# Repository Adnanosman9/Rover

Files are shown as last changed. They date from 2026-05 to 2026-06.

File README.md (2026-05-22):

<p align="center">
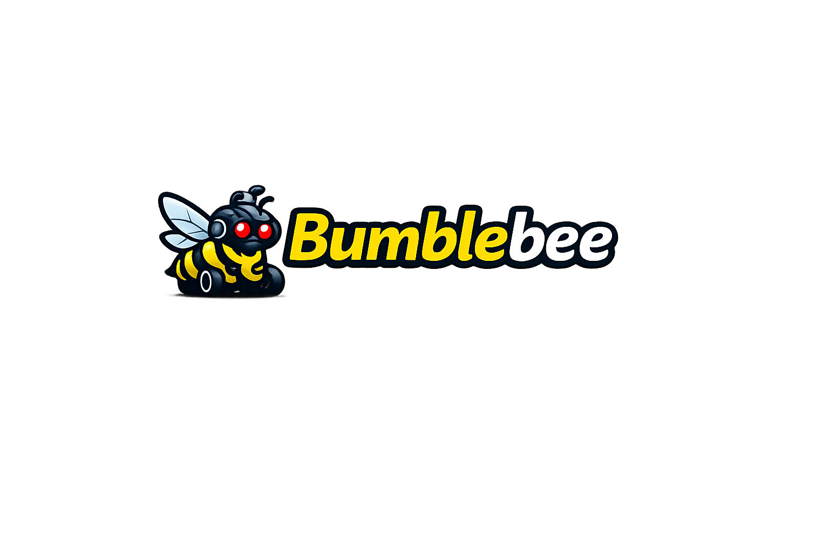
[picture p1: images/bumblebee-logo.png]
Bumblebee Logo
  
</p>

<h1 align="center">Bumblebee Rover</h1>

<p align="center">
Open-source modular autonomous rover platform based on the Sawppy Rover architecture,
adapted around affordable and locally available hardware in Bangladesh.
</p>

<p align="center">
  <a href="https://ohwr.org/cern_ohl_s_v2.txt">
    
  </a>
  <a href="https://hcb.hackclub.com/donations/start/bumblebee">
    
  </a>
  
  
</p>

Open-source modular autonomous rover chassis based on the [Sawppy Rover](https://github.com/Roger-random/Sawppy_Rover) architecture by [@Roger-random](https://github.com/Roger-random), redesigned around affordable and locally available hardware in Bangladesh.

---

<p align="center">
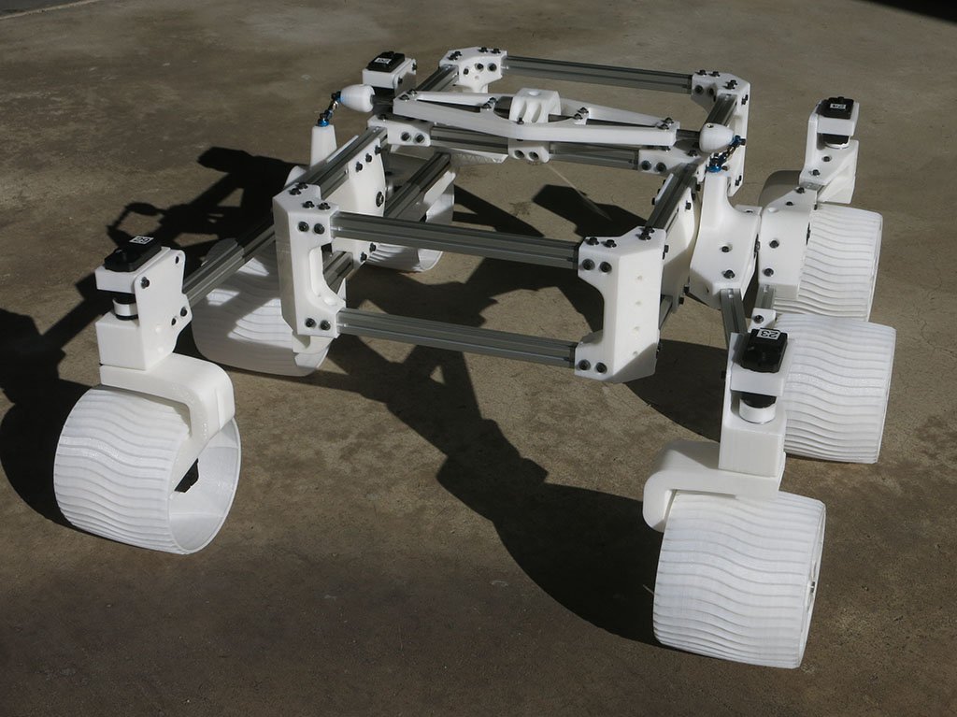
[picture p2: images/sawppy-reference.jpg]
Sawppy Rover Reference
  
</p>

### **Reference** [@Sawppy Rover](https://github.com/Roger-random/Sawppy_Rover/blob/main/docs/images/MechanicalChassis.jpg) by Roger Random, base chassis architecture this project is built on. 

---

## Overview

This is a student-led robotics project building a modular autonomous ground rover platform for robotics experimentation, autonomous navigation, and future competition adaptation.

Bumblebee is a derivative of the Sawppy Rover by Roger Random, replacing the original LX-16A smart servo drivetrain with JGB37-520 DC gear motors and Hiwonder LDX-227 PWM servos components that are significantly easier to source locally in Bangladesh at a fraction of the cost. Development files, CAD assets, documentation, and future electronics designs are intended to be published openly as the project progresses.

---

## Project Goals

- Build a functional rocker-bogie rover chassis adapted for local hardware
- Develop a reusable, modular rover platform for robotics experimentation
- Integrate ROS 2 for autonomous navigation and sensor fusion
- Publicly document the full engineering and prototyping process for other students and makers

---

## Key Features

- Rocker-bogie suspension system (Sawppy geometry, adapted mounts)
- Modular chassis architecture designed for payload expansion
- JGB37-520 12V 100RPM DC gear motor drivetrain (×6)
- Hiwonder LDX-227 PWM servo steering (×4)
- Standard 25T servo spline, no proprietary hardware
- Designed for ROS 2 integration and future autonomous navigation stack

---

## Major Changes from Sawppy

| Component | Sawppy Original | Bumblebee |
|---|---|---|
| Drive motor | LX-16A smart servo | JGB37-520 12V 100RPM DC gear motor |
| Steering | LX-16A smart servo | Hiwonder LDX-227 PWM servo |
| Motor control | Serial smart servo bus | BTS7960 |
| Servo spline | Proprietary | Standard 25T spline |
| Control MCU | - | Arduino or ESP |
| single board computer | - | Raspberry pi 4 4B |
| IMU | - | MPU-6050 |
| Hardware sourcing | Mostly imported | Locally available in Bangladesh |

---

## Hardware Stack

### Mobility
- 6× JGB37-520 12V 100RPM DC gear motors
- 4× Hiwonder LDX-227 PWM servos
- BTS7960 motor driver

### Structure
- Custom 3D printed components (PLA/PETG, ~3 kg)
- Aluminum extrusion frame
- Steel/aluminum shafts

### Electronics
- Raspberry Pi 4
- Arduino or ESP
- MPU-6050 IMU
- LiPo battery pack + BMS

### Software (Planned)
- ROS 2
- Autonomous navigation stack (GPS waypoints + SLAM)
- Sensor fusion
- Rover control interface

---

## Current Progress

### Completed
- Chassis architecture finalized
- Hardware selection completed
- Motor mount redesign
- Servo bracket redesign
- Steering linkage adaptation
- STEP files generated are available in [`/Step-files`](./Step-files)
- BOM completed
- Build log available in [`/Build log`](./Build%20log/architecture-journal.md)
- HCB fiscal sponsorship approved

### In Progress
- Structural component printing
- Chassis assembly

### Planned
- Drivetrain testing
- ROS 2 integration
- Autonomous navigation
- Field testing
- Payload expansion

---

## Why This Build Exists

Most capable open-source rover platforms - including the original Sawppy - rely on LX-16A or similar smart servos that are expensive and difficult to source reliably outside of the US, Europe, or China. Bumblebee is a direct answer to that problem: a full rocker-bogie rover platform adapted around hardware that is realistically accessible to students in Bangladesh.

The engineering tradeoffs are documented openly. This project is also intended to help other students and makers in similar situations adapt advanced robotics platforms to their local hardware ecosystem.

---

## Sponsorship

Bumblebee is fiscally sponsored by [Hack Club](https://hackclub.com), a 501(c)(3) nonprofit (EIN 81-2908499). **US donations are tax-deductible.**

We are currently seeking support for:

| What | Why it matters |
|---|---|
| Power and control | Batteries, converters, and motor drivers are currently major integration blockers |
| 3D printing | Structural parts, FDM in PLA/PETG |
| JGB37-520 motors + LDX-227 servos | Hard to source at consistent spec in Bangladesh |
| Sensors & compute | IMU, GPS, SBC for autonomous navigation stack |

For sponsorship details visit **→ [Sponsor page](https://adnanosman9.github.io/Bumblebee/sponsor.html)**
**→ [Donate directly via HCB](https://hcb.hackclub.com/donations/start/bumblebee)**

Sponsors receive logo placement on the project website and permanent credit in all documentation.

---

## Repository Structure

```
/
├── step-files/          # Fusion 360 source files and STEP exports
├── docs/         # Build logs and engineering notes
└── bom/          # Bill of materials
```
Additional firmware, electronics files, documentation, and testing data will be added progressively as development continues.
---

## License

Hardware designs in this repository are licensed under the **CERN Open Hardware Licence Version 2 - Strongly Reciprocal (CERN-OHL-S-2.0)**.

You are free to use, study, modify, and distribute this hardware and its documentation, provided that derivatives are released under the same license.

See [`LICENSE`](./LICENSE) for the full text, or visit [ohwr.org/cern_ohl_s_v2.txt](https://ohwr.org/cern_ohl_s_v2.txt).

---

## Acknowledgements

- [Roger Random (@Roger-random)](https://github.com/Roger-random) and the [Sawppy Rover](https://github.com/Roger-random/Sawppy_Rover) community — original architecture, suspension geometry, and open-source design philosophy
- [Hack Club HCB](https://hackclub.com/hcb) - fiscal sponsorship
- Open-source robotics and maker communities

---

## Author

**Adnan Osman** - [github.com/Adnanosman9](https://github.com/Adnanosman9)

Project website: [adnanosman9.github.io/Bumblebee](https://adnanosman9.github.io/Bumblebee/)

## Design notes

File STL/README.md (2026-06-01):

# Bill of Materials - Bumblebee Rover

> Based on the [Sawppy Rover](https://github.com/Roger-random/Sawppy_Rover) architecture by [@Roger-random](https://github.com/Roger-random), adapted for locally available hardware in Bangladesh.

---

## Printed Parts
~3 kg total filament (PLA or PETG)

| Qty | Part | Notes |
|-----|---|---|
| 88 | Clip2n125 | Print a few extra for spares |
| 12 | Clip3n20 | Print a few extra for spares |
| 6 | Wheel Hub | Print a few extra for spares |
| 4 | Servo Coupler | Print a few extra for spares |
| 4 | Servo Bracket | |
| 6 | Wheel | |
| 4 | Steering Knuckle | |
| 4 | Body Corner | |
| 2 | DiffBrace | |
| 2 | DiffLink | |
| 1 | DiffLower | |
| 1 | DiffUpper | |
| 2 | Rod Support | |
| 1 | Power Panel | |
| 2 | Fixed Knuckle | Mirrored |
| 2 | Front Corner | Mirrored |
| 2 | Rear Corner | Mirrored |
| 2 | Bogie Wheels | Mirrored |
| 2 | Bogie Body | Mirrored |
| 2 | Rocker | Mirrored |
| 2 | Rocker Body Mount | Mirrored |
| 2 | DiffEnd | Mirrored |
| 2 | Battery Tray | Mirrored |
| 6 | JGB37-520 Motor Bracket | Redesigned mount · not yet designed, pending physical measurements |
| 6 | JGB37-520 Motor Coupler | Wheel-to-motor connection · not yet designed, pending physical measurements |

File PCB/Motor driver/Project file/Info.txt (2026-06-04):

Project Title: 		Dual_Motor_Driver
Borard Title: 		Board1
PCB Title: 		PCB1
Time: 		2026-06-04 21:03:17

Borard Size: 		58.713mm x 60.025mm
Layers: 		Total 24, Copper 4

Devices: 		44
Footprints: 		33
Components: 		Total 125,Top Layer 105,Bottom Layer 20
Pads: 		Total 457, Top Side Table Stick 342,Bottom Side Table Stick 98,Metallized Hole 17, Nonmetallic Hole 0
Nets: 		Total 96, Unrouted 0
Test Point: 		Nets Total 96, Has Testpoint Nets 0, Testpoint Coverage 0%
 		Total 0, Top Side Testpoints 0, Bottom Side Testpoints 0

Slot Region: 		2
Vias: 		Total 526, Through Vias 526, Blind Or Buried Vais 0
CopperAreas: 		6
Length of Tracks: 		1732.224mm

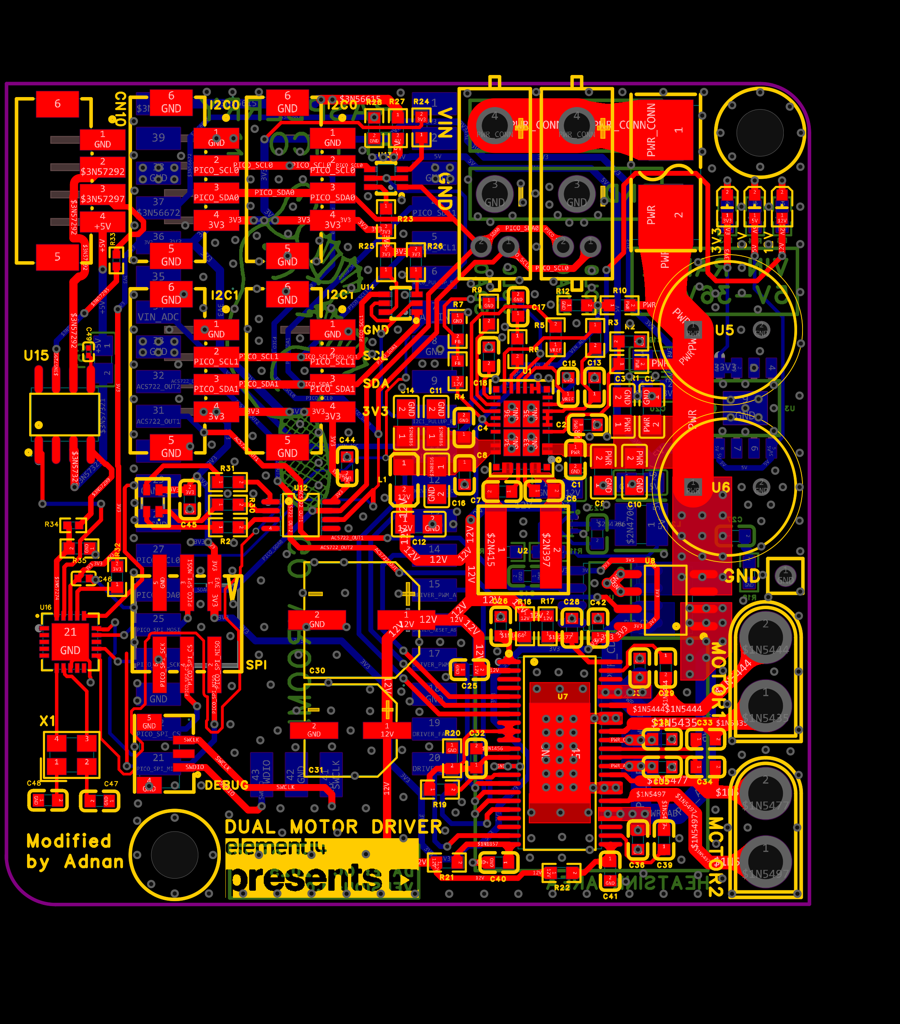
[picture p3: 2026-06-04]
PCB/Motor driver/images/Motor-Driver.png

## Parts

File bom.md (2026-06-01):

# Bill of Materials — Bumblebee Rover

> Based on the [Sawppy Rover](https://github.com/Roger-random/Sawppy_Rover) architecture by [@Roger-random](https://github.com/Roger-random), adapted for locally available hardware in Bangladesh.

---

## Printed Parts
~3 kg total filament (PLA or PETG)

| Qty | Part | Notes |
|-----|---|---|
| 88 | Clip2n125 | Print a few extra for spares |
| 12 | Clip3n20 | Print a few extra for spares |
| 6 | Wheel Hub | Print a few extra for spares |
| 4 | Servo Coupler | Print a few extra for spares |
| 4 | Servo Bracket | |
| 6 | Wheel | |
| 4 | Steering Knuckle | |
| 4 | Body Corner | |
| 2 | DiffBrace | |
| 2 | DiffLink | |
| 1 | DiffLower | |
| 1 | DiffUpper | |
| 2 | Rod Support | |
| 1 | Power Panel | |
| 2 | Fixed Knuckle | Mirrored |
| 2 | Front Corner | Mirrored |
| 2 | Rear Corner | Mirrored |
| 2 | Bogie Wheels | Mirrored |
| 2 | Bogie Body | Mirrored |
| 2 | Rocker | Mirrored |
| 2 | Rocker Body Mount | Mirrored |
| 2 | DiffEnd | Mirrored |
| 2 | Battery Tray | Mirrored |
| 6 | JGB37-520 Motor Bracket | Redesigned mount · not yet designed, pending physical measurements |
| 6 | JGB37-520 Motor Coupler | Wheel-to-motor connection · not yet designed, pending physical measurements |

---

## Shafts
Steel for differential shaft. Aluminum or steel for all others.

| Qty | Length (mm) | Part |
|-----|---|---|
| 1 | 300 | Differential Shaft |
| 6 | 50 | Wheel Axle Shaft |
| 4 | 61 | Steering Shaft |
| 2 | 66.5 | Suspension Bogie Pivot |
| 2 | 84 | Suspension Rocker Pivot |

---

## Hardware & Electronics

| Qty | Part | Notes |
|-----|---|---|
| 6 | JGB37-520 12V 100RPM DC Gear Motor | Drive |
| 4 | Hiwonder LDX-277 PWM Servo | Steering |
| 6 | Motor Shaft Couplers | JGB37-520 D-shaft compatible |
| 3 | BTS7960 43A Motor Driver Module | Paired motors per driver (2 motors × 3 drivers) |
| 1 | XIAO ESP32-C3 | Main control MCU |
| 1 | MPU-6050 | IMU |
| 1 | 12V LiPo Battery Pack | |
| 1 | Battery Management System (BMS) | 12V compatible |
| 30 | 608 Bearings | |
| 300 | M3×8mm Socket Head Screws | |
| 28 | M3×16mm Socket Head Screws | |
| 300 | M3 Washers + Nuts | |
| 100 | M3 Threaded Inserts | |
| 100 | 5/16" E-Clips | |
| 22 | M3×8 Set Screws | |
| 2 | Turnbuckles | Steering linkage |
| 40 | 1/4" Brass Screws | |

---

## Aluminum Extrusion
Standard 15mm or 20mm V-slot / T-slot profile.

| Qty | Length (mm) | Purpose |
|-----|---|---|
| 4 | 385 | Main body, lengthwise |
| 4 | 245 | Main body, widthwise |
| 1 | 238 | Differential fixed beam |
| 2 | 182 | Rocker joint to front wheel |
| 2 | 161 | Rocker joint to bogie joint |
| 2 | 122 | Bogie joint to middle wheel |
| 2 | 117 | Bogie joint to rear wheel |

---

## Notes

- **Motor Bracket & Coupler** — not yet designed. Will be modeled after physical parts are printed and measured.
- **BTS7960 wiring** — 3 drivers handle 6 motors in pairs (left-front+right-front, left-mid+right-mid, left-rear+right-rear). Each driver needs RPWM, LPWM, R_EN, L_EN from the ESP32-C3 — 12 GPIO pins total for drive.
- **608 bearings** — standard inline skate bearings, widely available locally.
- Printed part STEP files: [`/cad`](./cad)

---

*Bumblebee is fiscally sponsored by [Hack Club HCB](https://hcb.hackclub.com/donations/start/bumblebee) (501(c)(3) · EIN 81-2908499). Manufacturing sponsorships welcome — [sponsor page](https://adnanosman9.github.io/Bumblebee/sponsor.html).*

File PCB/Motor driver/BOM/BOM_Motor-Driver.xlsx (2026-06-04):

No. | Quantity | Comment | Designator | Footprint | Value | Manufacturer Part | Manufacturer | Supplier Part | Supplier | Category | Primary Category | LCSC Price | LCSC Stock | JLCPCB Stock | JLCPCB Price | Layer | Mounting Style | Pin Count | Add into BOM | Convert to PCB | 3D Model Title | Device | Name | Unique ID | Brand | Belt length
1 | 1 | 1PinHeader | 1PinHeader | 1PinHeader |  |  |  |  |  | Symbols Padronizados: | Symbols Padronizados | 0.0183 |  |  |  | T | DIP | 1 | yes |  |  | 1PinHeader |  | gge247
2 | 13 | 100nF | C1,C2,C4,C6,C7,C8,C18,C32,C35,C36,C37,C38,C42 | C0603 | 100nF | CL10B104KB8NNNC | SAMSUNG(三星) | C1591 | LCSC | Capacitors:Multilayer Ceramic Capacitors MLCC - SMD/SMT | Capacitors |  |  | 1077047 | 0.001 | T | SMT | 2 | yes |  | C0603_L1.6-W0.8-H0.8 | CL10B104KB8NNNC | 100nF | gge153,gge154,gge159,gge161,gge162,gge170,gge171,gge203,gge219,gge220,gge221,gge222,gge231
3 | 4 | 10uF | C3,C5,C9,C10 | C0805 | 10uF |  |  |  |  | Capacitors:Multilayer Ceramic Capacitors MLCC - SMD/SMT | Capacitors | 0.0183 |  |  |  | T | SMT | 2 | yes |  | C0805_L2.0-W1.3-H1.3 | CAP_0805 | 10uF | gge149,gge150,gge151,gge152
4 | 4 | 22uF | C11,C12,C14,C16 | C0805 | 22uF | CL21A226MAYNNNE | SAMSUNG(三星) | C602037 | LCSC | Capacitors:Multilayer Ceramic Capacitors MLCC - SMD/SMT | Capacitors |  |  | 1952 | 0.015 | T | SMT | 2 | yes |  | C0805_L2.0-W1.3-H1.3 | CL21A226MAYNNNE | 22uF | gge163,gge164,gge165,gge167
5 | 1 | 4.7uF | C13 | C0603 | 4.7uF |  |  |  |  | Capacitors:Multilayer Ceramic Capacitors MLCC - SMD/SMT | Capacitors | 0.0183 |  |  |  | T | SMT | 2 | yes |  | C0603_L1.6-W0.8-H0.8 | CAP_0603 | 4.7uF | gge243_1
6 | 1 | 470nF | C15 | C0603 | 470nF |  |  |  |  | Capacitors:Multilayer Ceramic Capacitors MLCC - SMD/SMT | Capacitors | 0.0183 |  |  |  | T | SMT | 2 | yes |  | C0603_L1.6-W0.8-H0.8 | CAP_0603 | 470nF | gge243
7 | 1 | 22nF | C17 | C0603 | 22nF |  |  |  |  | Capacitors:Multilayer Ceramic Capacitors MLCC - SMD/SMT | Capacitors | 0.0183 |  |  |  | T | SMT | 2 | yes |  | C0603_L1.6-W0.8-H0.8 | CAP_0603 | 22nF | gge158
8 | 5 | 22uF | C19,C20,C21,C22,C24 | C0805 | 22uF | CL21A226MAYNNNE | SAMSUNG(三星) | C602037 | LCSC | Capacitors:Multilayer Ceramic Capacitors MLCC - SMD/SMT | Capacitors |  |  | 1952 | 0.015 | B | SMT | 2 | yes |  | C0805_L2.0-W1.3-H1.3 | CL21A226MAYNNNE | 22uF | gge179,gge180,gge189,gge193,gge197
9 | 2 | 100nF | C23,C43 | C0603 | 100nF | CL10B104KB8NNNC | SAMSUNG(三星) | C1591 | LCSC | Capacitors:Multilayer Ceramic Capacitors MLCC - SMD/SMT | Capacitors |  |  | 1077047 | 0.001 | B | SMT | 2 | yes |  | C0603_L1.6-W0.8-H0.8 | CL10B104KB8NNNC | 100nF | gge192,gge200
10 | 9 | 1uF | C25,C26,C28,C29,C33,C34,C39,C40,C41 | C0603 | 1uF | CL10A105KA8NNNC | SAMSUNG(三星) | C5673 | LCSC | Capacitors:Multilayer Ceramic Capacitors MLCC - SMD/SMT | Capacitors |  |  | 6350 | 0.0014 | T | SMT | 2 | yes |  | C0603_L1.6-W0.8-H0.8 | CL10A105KA8NNNC | 1uF | gge205,gge206,gge208,gge210,gge212,gge213,gge215,gge216,gge217
11 | 1 | 10nF | C27 | C0603 | 10nF |  |  |  |  | Capacitors:Multilayer Ceramic Capacitors MLCC - SMD/SMT | Capacitors | 0.0183 |  |  |  | B | SMT | 2 | yes |  | C0603_L1.6-W0.8-H0.8 | CAP_0603 | 10nF | gge227
12 | 1 | 330uF | C30 | CAP-SMD_BD8.0-L8.3-W8.3-FD | 330uF | EMK1EM331FB0D00R | AISHI(艾华集团) | C5289732 | LCSC | Capacitors:Aluminum Electrolytic Capacitors - SMD | Capacitors |  |  | 159 | 0.0179 | T | SMT | 2 | yes |  | CAP-SMD_BD8.0-L8.3-W8.3-FD | EMK1EM331FB0D00R | 330uF | gge218
13 | 1 | 47uF | C31 | CAP-SMD_BD6.3-L6.6-W6.6-LS7.8-FD | 47uF | EEV476M035S9GAA | KEMET(基美) | C3829743 | LCSC | Capacitors:Aluminum Electrolytic Capacitors - SMD | Capacitors |  |  | 85 | 0.0349 | T | SMT | 2 | yes |  | CAP-SMD_BD6.3-L6.6-W6.6-LS7.8-FD | EEV476M035S9GAA | 47uF | gge214
14 | 2 | 100nF | C44,C45 | C0603 |  | 0603F104Z500CT | Walsin(华新科) | C83060 | LCSC |  |  |  |  | 0 | 0.003 | T | SMT | 2 | yes |  |  | 100nF | 100nF | gged6dc231d1b0ccea6,gged6dc231d1b0ccea6_1
15 | 1 | 100nF | C46 | C0402 | 100nF | FN15B104K250PNG | PSA(信昌电陶) | C394158 | LCSC | Capacitors:Multilayer Ceramic Capacitors MLCC - SMD/SMT | Capacitors |  |  | 6793 | 0.0004 | T | SMT | 2 | yes |  | C0402_L1.0-W0.5-H0.5 | FN15B104K250PNG | 100nF | gge250
16 | 2 | 22pF | C47,C48 | C0603 | 22pF | 0603N220G500CT | Walsin(华新科) | C388039 | LCSC | Capacitors:Multilayer Ceramic Capacitors MLCC - SMD/SMT | Capacitors |  |  | 655 | 0.0013 | T | SMT | 2 | yes |  | C0603_L1.6-W0.8-H0.8 | 0603N220G500CT | 22pF | gge253,gge254
17 | 1 | 100nF | C49 | C0201 | 100nF | FN03B104K160PLG | PSA(信昌电陶) | C525189 | LCSC | Capacitors:Multilayer Ceramic Capacitors MLCC - SMD/SMT | Capacitors |  |  | 847 | 0.0003 | T | SMT | 2 | yes |  | C0201_L0.6-W0.3-H0.3 | FN03B104K160PLG | 100nF | gge262
18 | 1 | 100nF | C51 | C0805 | 100nF | CC0805KRX7R9BB104 | YAGEO(国巨) | C49678 | LCSC | Capacitors:Multilayer Ceramic Capacitors MLCC - SMD/SMT | Capacitors |  |  | 8667805 | 0.0014 | B | SMT | 2 | yes |  | C0805_L2.0-W1.3-H1.3 | CC0805KRX7R9BB104 | 100nF | gge264
19 | 2 | XT30U-M | CN1,CN2 | CONN-TH_XT30U-M |  | XT30U-M | AMASS(艾迈斯) | C99101 | LCSC | Industrial control electrical:plug | Industrial control electrical |  |  | 54944 | 0.0344 | T | DIP | 2 | yes |  | CONN-TH_XT30U-M | XT30U-M | XT30U-M | gge137,gge137_1 | 艾迈斯 | -
20 | 5 | WAFER-PH2.0-4PLB | CN3,CN4,CN5,CN6,CN10 | CONN-SMD_4P-P2.00_WAFER-200L-4A |  | WAFER-PH2.0-4PLB | XUNPU(讯普) | C3029433 | LCSC | Connectors:Wire To Board Connector | Connectors |  |  | 17720 | 0.0158 | T | SMT | 6 | yes |  | CONN-SMD_4P-P2.00_WAFER-200L-4A | WAFER-PH2.0-4PLB | WAFER-PH2.0-4PLB | gge78_1,gge78_2,gge78_3,gge78_4,gge261
21 | 1 | 98424-G52-06ALF | CN7 | CONN-SMD_98424-G52-06ALF |  | 98424-G52-06ALF | Amphenol | C180222 | LCSC | Connectors:Wire To Board Connector | Connectors |  |  | 832 | 0.1057 | T | SMT | 6 | yes |  | CONN-SMD_L8.0-W6.1-H6.2-P2.0-2x3P | 98424-G52-06ALF | 98424-G52-06ALF | gge244
22 | 1 | 0154001.DR | F1 | FUSE-SMD_L9.8-W5.1 |  | 0154001.DR | Littelfuse(美国力特) | C206908 | LCSC | Circuit Protection:Disposable fuses | Circuit Protection |  |  | 2365 | 0.2505 | T | SMT | 2 | yes |  | FUSE-SMD_L10.0-W5.0-H3.8 | 0154001.DR | 0154001.DR | gge4
23 | 1 | MPZ2012S221ATD25 | L1 | L0805 |  | MPZ2012S221ATD25 | TDK | C307778 | LCSC | Filters:Ferrite Beads | Filters |  |  | 75778 | 0.006 | T | SMT | 2 | yes |  | R0805_L2.0-W1.3-H0.6 | MPZ2012S221ATD25 | MPZ2012S221ATD25 | gge166
24 | 1 | ME3220-472MLC | L2 | IND-SMD_L3.2-W2.8 |  | ME3220-472MLC | Coilcraft(线艺) | C19276064 | LCSC | Inductors, Coils, Chokes:Power Inductors | Inductors, Coils, Chokes |  |  | 0 | 0.1544 | B | SMT | 2 | yes |  |  | ME3220-332MLC | ME3220-472MLC | gge187
25 | 3 | LED_0603-R | LED1,LED2,LED3 | LED0603-R-RD |  |  |  |  |  | Optocoupler/LED/Digital Tube/Photoelectric Device:Light Emitting Diodes (LED) | Optocoupler/LED/Digital Tube/Photoelectric Device | 0.0183 |  |  |  | T | SMT | 2 | yes |  | LED0603-R-RD | LED_0603-R |  | gge181,gge184,gge195
26 | 1 | 150066M153000 | LED4 | 150066M153000 |  |  |  |  |  |  |  | 0.0183 |  |  |  | T | SMT | 4 | yes |  |  | 150066M153000 | 150066M153000 | gge5cda8d9033f7c28f
27 | 2 | M3 Screw | MH1,MH2 | MOUNTINGHOLE-M3 |  | M3 Screw |  |  |  |  |  | 0.0183 |  |  |  | T | SMT | 0 | yes |  |  | M3 Screw | M3 Screw | gge18f16b016255e95a,gge18f16b016255e95a_1
28 | 2 | XT30(2+2)PB-M.G.B | PowerConnector1,PowerConnector2 | CONN-TH_XT30PB-M |  | XT30(2+2)PB-M.G.B | AMASS(艾迈斯) | C19268029 | LCSC | Industrial control electrical:plug | Industrial control electrical |  |  | 27349 | 0.0642 | T | DIP | 4 | yes |  | CONN-TH_XT30PB-M | XT30(2+2)PB-M.G.B | XT30(2+2)PB-M.G.B | gge2,gge2_1
29 | 1 | 120k | R1 | R0603 | 120k |  |  |  |  | Resistors:Chip Resistor - Surface Mount | Resistors | 0.0183 |  |  |  | T | SMT | 2 | yes |  | R0603 | Res_0603 | 120k | MCWR06X2703FTL
30 | 4 | 100k | R2,R3,R5,R10 | R0603 | 100k |  |  |  |  | Resistors:Chip Resistor - Surface Mount | Resistors | 0.0183 |  |  |  | T | SMT | 2 | yes |  | R0603 | Res_0603 | 100k | gge176,MCMR06X1003FTL,MCMR06X1003FTL_1,MCMR06X1003FTL_2
31 | 1 | 110k | R4 | R0603 | 110k |  |  |  |  | Resistors:Chip Resistor - Surface Mount | Resistors | 0.0183 |  |  |  | T | SMT | 2 | yes |  | R0603 | Res_0603 | 110k | gge168
32 | 1 | 5.1k | R6 | R0603 | 5.1k |  |  |  |  | Resistors:Chip Resistor - Surface Mount | Resistors | 0.0183 |  |  |  | T | SMT | 2 | yes |  | R0603 | Res_0603 | 5.1k | gge157
33 | 2 | 10K | R7,R12 | R0603 | 10K |  |  |  |  | Resistors:Chip Resistor - Surface Mount | Resistors | 0.0183 |  |  |  | T | SMT | 2 | yes |  | R0603 | Res_0603 | 10K | gge169,gge177
34 | 1 | 4.7k | R8 | R0603 | 4.7k |  |  |  |  | Resistors:Chip Resistor - Surface Mount | Resistors | 0.0183 |  |  |  | B | SMT | 2 | yes |  | R0603 | Res_0603 | 4.7k | gge185
35 | 1 | 143k | R9 | R0603 | 143k |  |  |  |  | Resistors:Chip Resistor - Surface Mount | Resistors | 0.0183 |  |  |  | T | SMT | 2 | yes |  | R0603 | Res_0603 | 143k | gge160
36 | 1 | 53k | R11 | R0603 | 53k |  |  |  |  | Resistors:Chip Resistor - Surface Mount | Resistors | 0.0183 |  |  |  | B | SMT | 2 | yes |  | R0603 | Res_0603 | 53k | gge190
37 | 1 | 1k | R13 | R0603 | 1k |  |  |  |  | Resistors:Chip Resistor - Surface Mount | Resistors | 0.0183 |  |  |  | B | SMT | 2 | yes |  | R0603 | Res_0603 | 1k | gge182
38 | 1 | 2k | R14 | R0603 | 2k |  |  |  |  | Resistors:Chip Resistor - Surface Mount | Resistors | 0.0183 |  |  |  | B | SMT | 2 | yes |  | R0603 | Res_0603 | 2k | gge196
39 | 1 | 10K | R15 | R0603 | 10K |  |  |  |  | Resistors:Chip Resistor - Surface Mount | Resistors | 0.0183 |  |  |  | B | SMT | 2 | yes |  | R0603 | Res_0603 | 10K | gge191
40 | 4 | 5R | R16,R17,R21,R22 | R0603 | 5R |  |  |  |  | Resistors:Chip Resistor - Surface Mount | Resistors | 0.0183 |  |  |  | T | SMT | 2 | yes |  | R0603 | Res_0603 | 5R | gge204,gge207,gge209,gge211
41 | 1 | 3R3 | R18 | R0603 | 3R3 |  |  |  |  | Resistors:Chip Resistor - Surface Mount | Resistors | 0.0183 |  |  |  | B | SMT | 2 | yes |  | R0603 | Res_0603 | 3R3 | gge228
42 | 1 | 24K | R19 | R0603 | 24K |  |  |  |  | Resistors:Chip Resistor - Surface Mount | Resistors | 0.0183 |  |  |  | T | SMT | 2 | yes |  | R0603 | Res_0603 | 24K | gge202
43 | 1 | 1R | R20 | R0603 | 1R |  |  |  |  | Resistors:Chip Resistor - Surface Mount | Resistors | 0.0183 |  |  |  | T | SMT | 2 | yes |  | R0603 | Res_0603 | 1R | gge201
44 | 4 | 4k7 | R23,R24,R25,R26 | R0603 | 4k7 |  |  |  |  | Resistors:Chip Resistor - Surface Mount | Resistors | 0.0183 |  |  |  | T | SMT | 2 | yes |  | R0603 | Res_0603 | 4k7 | gge237,gge238,gge239,gge240
45 | 2 | 0R | R27,R28 | R0603 | 0R |  |  |  |  | Resistors:Chip Resistor - Surface Mount | Resistors | 0.0183 |  |  |  | T | SMT | 2 | yes |  | R0603 | Res_0603 | 0R | gge235_1,gge236_1
46 | 3 | 1kΩ | R29,R30,R31 | R0603 | 1kΩ | RT0603BRD071KL | YAGEO(国巨) | C110776 | LCSC | Resistors:Chip Resistor - Surface Mount | Resistors |  |  | 250303 | 0.0034 | T | SMT | 2 | yes |  | R0603 | RT0603BRD071KL | 1kΩ | gge110_1,gge110_2,gge110_3
47 | 1 | 10kΩ | R32 | R0603 | 10kΩ | 0603WAF1002T5E | UNI-ROYAL(厚声) | C25804 | LCSC | Resistors:Chip Resistor - Surface Mount | Resistors |  |  | 7628883 | 0.0005 | T | SMT | 2 | yes |  | R0603 | 0603WAF1002T5E | 10kΩ | gge251
48 | 1 | 120Ω | R33 | R0402 | 120Ω | 0402WGF1200TCE | UNI-ROYAL(厚声) | C25079 | LCSC | Resistors:Chip Resistor - Surface Mount | Resistors |  |  | 551149 | 0.0002 | T | SMT | 2 | yes |  | R0402_L1.0-W0.5-H0.4 | 0402WGF1200TCE | 120Ω | gge263
49 | 1 | 2.2kΩ | R34 | R0402 | 2.2kΩ | RMC04022.2K1%N | Tyohm(幸亚电阻) | C325418 | LCSC | Resistors:Chip Resistor - Surface Mount | Resistors |  |  | 1186 | 0.0005 | T | SMT | 2 | yes |  | R0402_L1.0-W0.5-H0.4 | RMC04022.2K1%N | 2.2kΩ | gge256
50 | 1 | 3.3kΩ | R35 | R0603 | 3.3kΩ | RMC06033.3K1%N | Tyohm(幸亚电阻) | C269710 | LCSC | Resistors:Chip Resistor - Surface Mount | Resistors |  |  | 3955 | 0.0006 | T | SMT | 2 | yes |  | R0603 | RMC06033.3K1%N | 3.3kΩ | gge257
51 | 3 | Test-Point | TP_3V1,TP_5V,TP_12V | Test-Point-0.5mm |  |  |  |  |  |  |  | 0.0183 |  |  |  | T | SMT | 1 | yes |  |  | Test-Point |  | gge172,gge183,gge194
52 | 1 | LT8350RV#PBF | U1 | LQFN-32_L6.0-W4.0-P0.50-BL-EP_LT8350RV |  | LT8350RV#PBF | ADI(亚德诺) | C5367366 | LCSC | Power Management (PMIC):DC-DC Converters | Power Management (PMIC) |  |  | 1 | 1.8268 | T | SMT | 36 | yes |  | LQFN-32_L6.0-W4.0-P0.50-BL-EP_LT8350RV | LT8350RV#PBF_C5367366 | LT8350RV#PBF | gge146
53 | 1 | 6.8uH | U2 | IND-SMD_L6.6-W6.4 | 6.8uH | XAL6060-682MEC | Coilcraft(线艺) | C5355913 | LCSC | Inductors, Coils, Chokes:Power Inductors | Inductors, Coils, Chokes |  |  | 3011 | 0.6307 | T | SMT | 2 | yes |  | IND-SMD_L6.6-W6.4-H2.9 | XAL6060-682MEC | 6.8uH | gge147
54 | 1 | BD33HC0VEFJ-ME2 | U3 | HTSOP-J8_L4.9-W3.9-P1.27-LS6.0-BL-EP |  | BD33HC0VEFJ-ME2 | ROHM(罗姆) | C22202420 | LCSC | Power Management (PMIC):Voltage Regulators - Linear, Low Drop Out (LDO) Regulators | Power Management (PMIC) |  |  | 0 | 0.078 | B | SMT | 9 | yes |  | HTSOP-J8_L4.9-W3.9-H1.0-P1.27-LS6.0-BL-EP | BD33HC0VEFJ-ME2 | BD33HC0VEFJ-ME2 | gge178
55 | 1 | AP62200Z6-7 | U4 | SOT-563_L1.6-W1.2-P0.50-LS1.6-BL |  | AP62200Z6-7 | DIODES(美台) | C2158024 | LCSC | Power Management (PMIC):DC-DC Converters | Power Management (PMIC) |  |  | 1947 | 0.0296 | B | SMT | 6 | yes |  | SOT-563-6P_L1.6-W1.2-H0.6-LS1.6-P0.50 | AP62200Z6-7 | AP62200Z6-7 | gge186
56 | 2 | ECA1HM471B | U5,U6 | CAPPRD500W65D1000H2200 |  |  |  |  |  |  |  | 0.0183 |  |  |  | T | DIP | 2 | yes |  |  | ECA1HM471B | ECA1HM471B | gge233,gge234
57 | 1 | DRV8412DDWR | U7 | HTSSOP-44_L14.0-W6.1-P0.64-LS8.1-BL-EP |  | DRV8412DDWR | TI(德州仪器) | C79852 | LCSC | Motor Driver ICs:Stepper Motor Driver | Motor Driver ICs |  |  | 1867 | 0.8875 | T | SMT | 45 | yes |  | HTSSOP-44_L14.0-W6.1-H1.2-LS8.2-P0.64 | DRV8412DDWR | DRV8412DDWR | gge198
58 | 1 | ACS722LLCTR-10AB-T | U8 | SOIC-8_L4.9-W3.9-P1.27-LS6.0-BL |  | ACS722LLCTR-10AB-T | ALLEGRO(美国埃戈罗) | C459316 | LCSC | Magnetic Sensors:Current Sensors | Magnetic Sensors |  |  | 300 | 0.5787 | T | SMT | 8 | yes |  | SOIC-8_L4.9-W3.9-H1.7-LS6.0-P1.27 | ACS722LLCTR-10AB-T | ACS722LLCTR-10AB-T | gge230
59 | 1 | ACS722LLCTR-10AB-T | U9 | SOIC-8_L4.9-W3.9-P1.27-LS6.0-BL |  | ACS722LLCTR-10AB-T | ALLEGRO(美国埃戈罗) | C459316 | LCSC | Magnetic Sensors:Current Sensors | Magnetic Sensors |  |  | 300 | 0.5787 | B | SMT | 8 | yes |  | SOIC-8_L4.9-W3.9-H1.7-LS6.0-P1.27 | ACS722LLCTR-10AB-T | ACS722LLCTR-10AB-T | gge199
60 | 1 | BM03B-SRSS-TB(LF)(SN) | U10 | CONN-SMD-3P-P1.00_BM03B-SRSS-TB-LF-SN |  | BM03B-SRSS-TB(LF)(SN) | JST | C160389 | LCSC | Connectors:Wire To Board Connector | Connectors |  |  | 12572 | 0.0394 | T | SMT | 5 | yes |  | CONN-SMD_SR1.00-LS-3P | BM03B-SRSS-TB(LF)(SN) | BM03B-SRSS-TB(LF)(SN) | gge246
61 | 1 | PICO | U11 | COMM-SMD_L51.0-W21.0-P2.54_SC0916 |  | PICO | Raspberry Pi(树莓派) | C7203002 | LCSC | 开发板/开发工具:树莓派 | 开发板/开发工具 |  |  | 569 | 1.195 | B | SMT | 43 | yes |  |  | PICO | PICO | gge245
62 | 1 | PCA9633DP1,118 | U12 | TSSOP-8_L3.0-W3.0-P0.65-LS4.9-BL |  | PCA9633DP1,118 | NXP(恩智浦) | C88381 | LCSC | LED Drivers:LED Drivers | LED Drivers |  |  | 78 | 0.3466 | T | SMT | 8 | yes |  | TSSOP-8_L3.0-W3.0-H1.1-LS4.9-P0.65 | PCA9633DP1,118 | PCA9633DP1,118 | gge145
63 | 2 | RN2905,LF(CT | U13,U14 | SOT-323-6_L2.0-W1.3-P0.65-LS2.1-BR |  | RN2905,LF(CT | TOSHIBA(东芝) | C5732699 | LCSC | Transistors/Thyristors:Digital Transistors | Transistors/Thyristors |  |  | 0 | 0.011 | T | SMT | 6 | yes |  | SOT-323-6_L2.0-W1.3-P0.65-LS2.1-BR | RN2905,LF(CT | RN2905,LF(CT | gge241,gge242
64 | 1 | TJA1050TM/TR | U15 | SOIC-8_L4.9-W3.9-P1.27-LS6.0-BL |  | TJA1050TM/TR | HGSEMI(华冠) | C42370273 | LCSC | Interface:CAN Transceivers | Interface |  |  | 7651 | 0.0742 | T | SMT | 8 | yes |  | SOIC-8_L4.9-W3.9-H1.7-LS6.0-P1.27 | TJA1050TM/TR | TJA1050TM/TR | gge249
65 | 1 | MCP2515T-I/ML | U16 | QFN-20_L4.0-W4.0-P0.50-TL-EP2.7 |  | MCP2515T-I/ML | MICROCHIP(美国微芯) | C96140 | LCSC | Interface:CAN Controllers | Interface |  |  | 3453 | 0.2593 | T | SMT | 21 | yes |  | QFN-20_L4.0-W4.0-H0.8-P0.50 | MCP2515T-I/ML | MCP2515T-I/ML | gge248
66 | 1 | 16MHz | X1 | CRYSTAL-SMD_4P-L3.2-W2.5-BL | 16MHz | X322516MLB4SI | YXC(扬兴晶振) | C13738 | LCSC | Crystals, Oscillators, Resonators:Crystals | Crystals, Oscillators, Resonators |  |  | 353443 | 0.0107 | T | SMT | 4 | yes |  | CRYSTAL-SMD_4P-L3.2-W2.5-BL | X322516MLB4SI | 16MHz | gge252

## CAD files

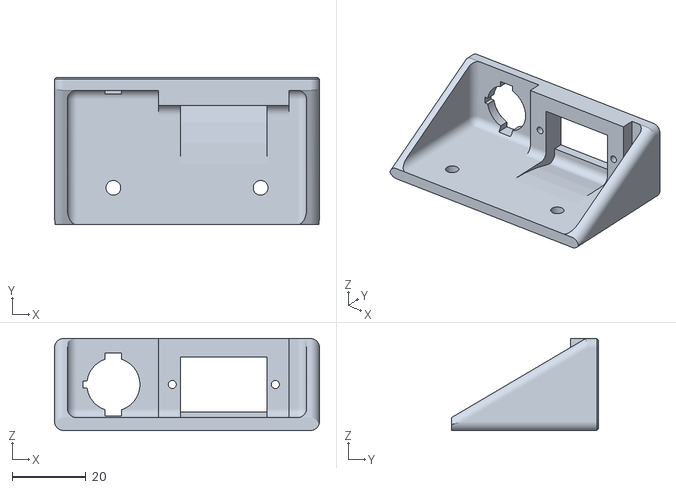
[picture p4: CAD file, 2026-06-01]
STL/Power Panel.stl
72.0 x 40.0 x 25.0

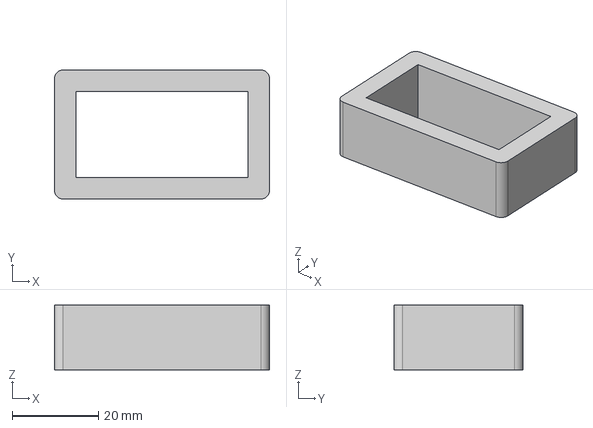
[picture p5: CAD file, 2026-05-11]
Step-files/servo bracket.step
50.0 x 30.0 x 15.0 mm

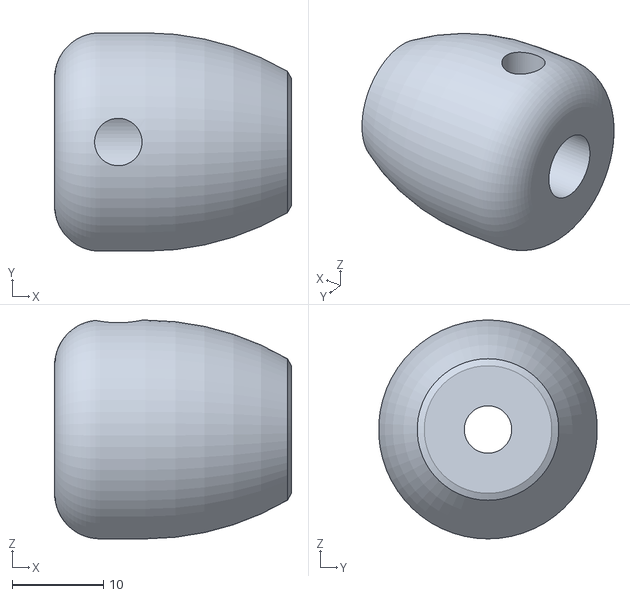
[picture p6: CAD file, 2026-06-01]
STL/DiffLink.stl
26.0 x 24.0 x 24.0

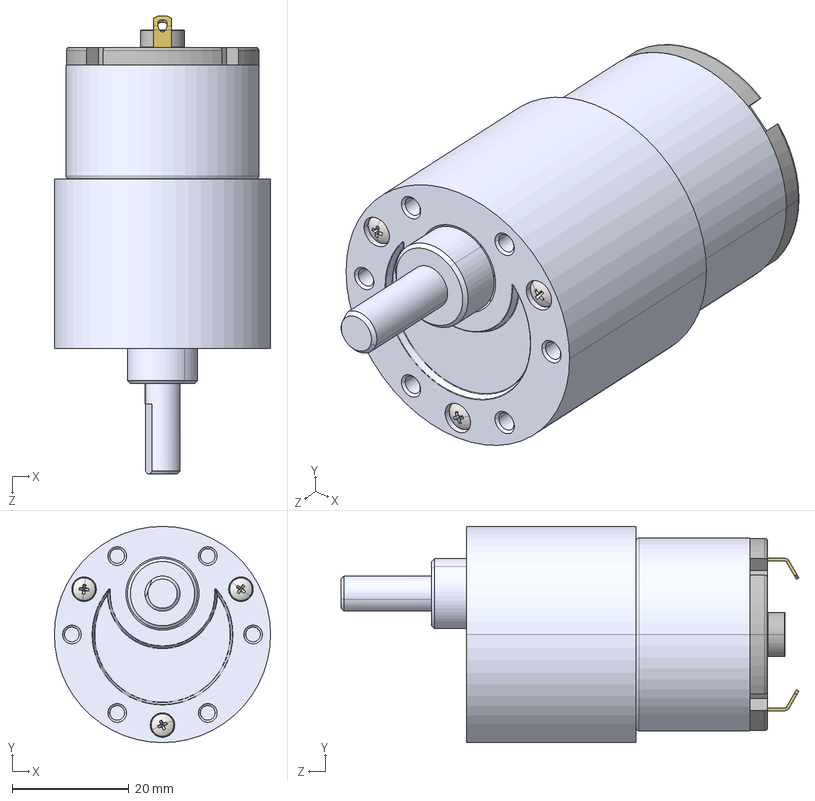
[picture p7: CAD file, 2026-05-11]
Step-files/JGB37-520.STEP
37.0 x 37.0 x 78.4 mm
GEARED BODY, MOTOR, JGB37-520
DC MOTOR, JGB37-520
MOTOR SHAFT, JGB37-520
SHAFT COUPLER, JGB37-520
COUPLING BRACKET, GEARED BODY TO DC MOTOR, JGB37-520
PLASTIC COVER, DC MOTOR, JGB37-520
CONNECTION, DC MOTOR, JGB37-520 x 2
pan cross head_am_B18.6.7M - M2 x 0.4 x 25 Type I Cross Recessed PHMS --25N x 3

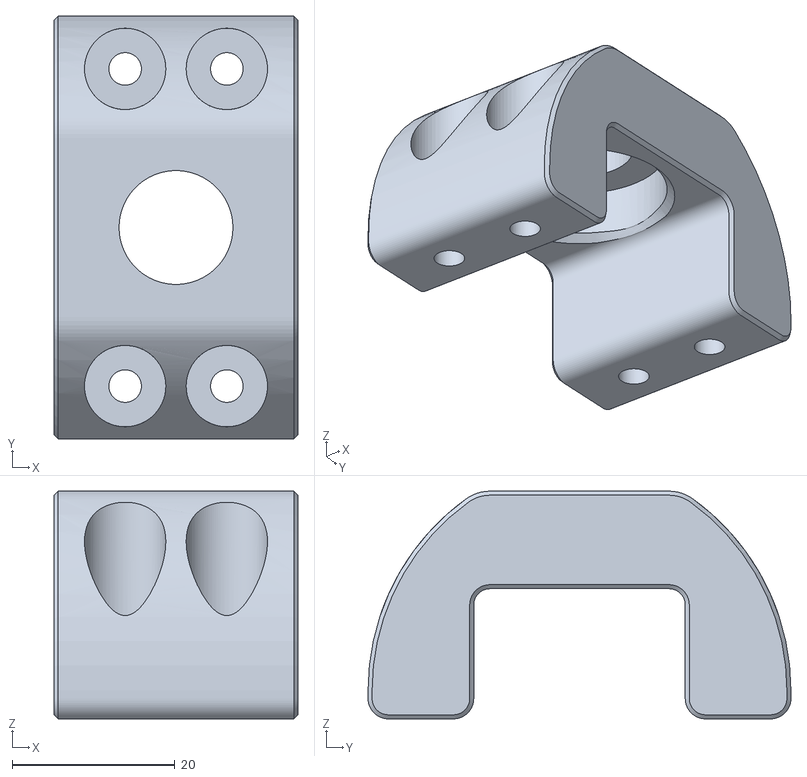
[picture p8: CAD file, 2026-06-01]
STL/DiffUpper.stl
30.0 x 52.0 x 28.0

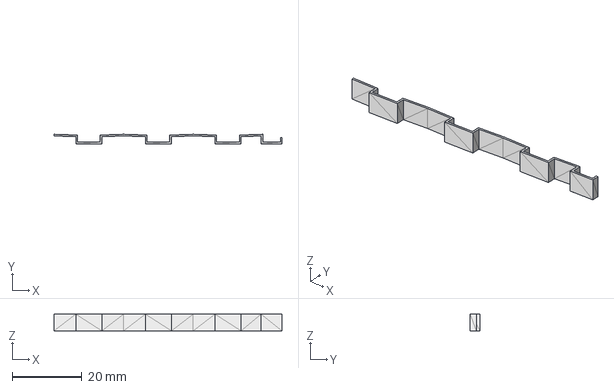
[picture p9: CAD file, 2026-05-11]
Step-files/Clip3n20.step
65.5 x 2.75 x 4.80 mm

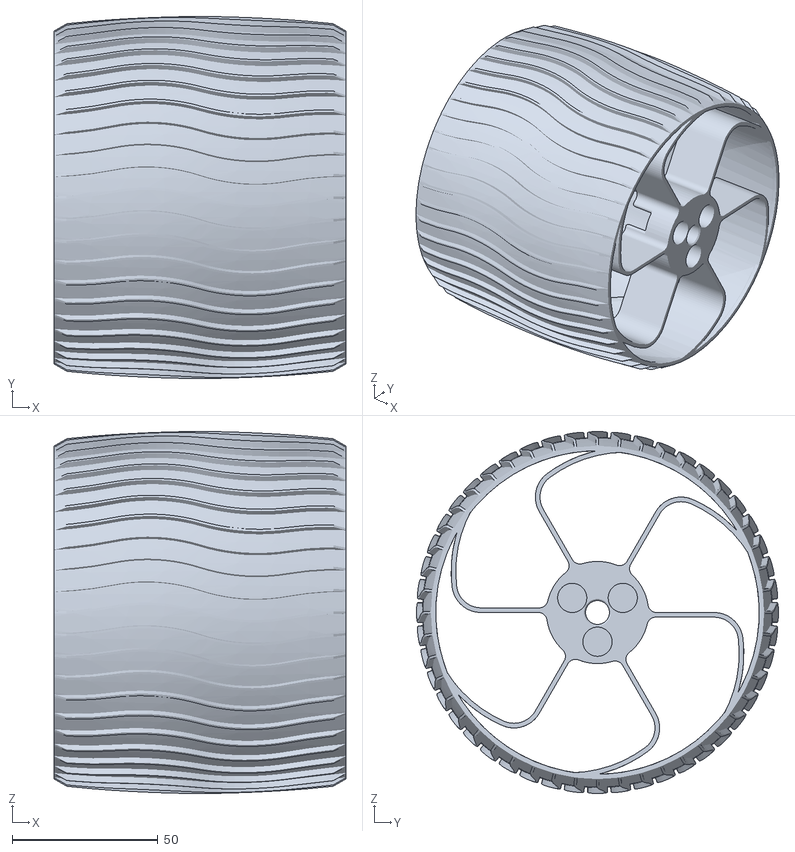
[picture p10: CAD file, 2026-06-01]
STL/Wheel.stl
100.0 x 124.0 x 124.0

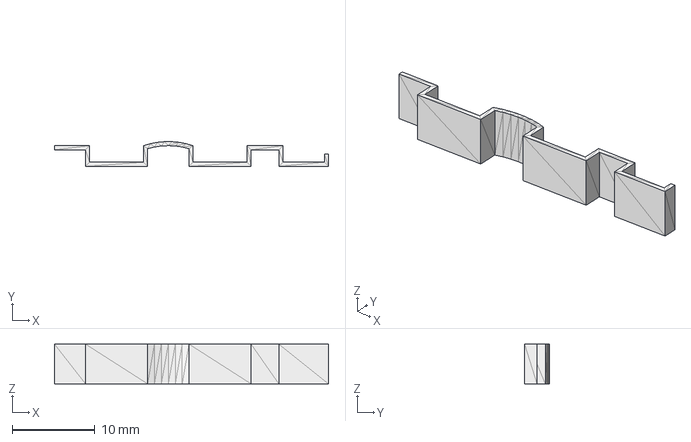
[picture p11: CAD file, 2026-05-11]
Step-files/Clip2n125.step
33.1 x 2.99 x 4.80 mm

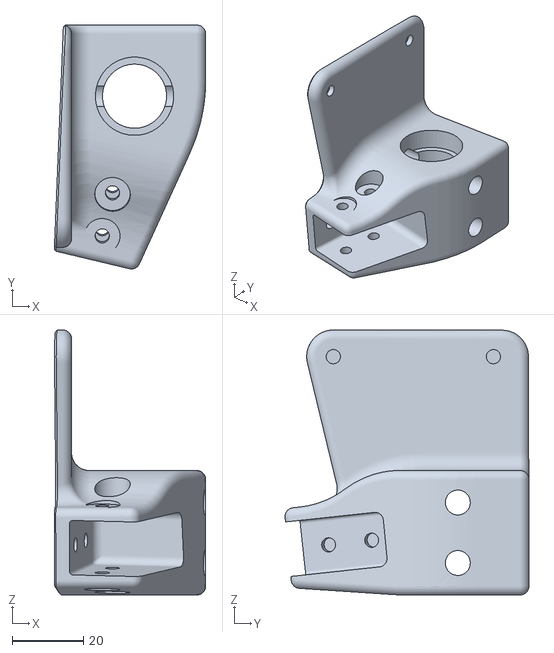
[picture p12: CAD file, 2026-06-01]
STL/Rear Corner.stl
42.6 x 68.6 x 74.5

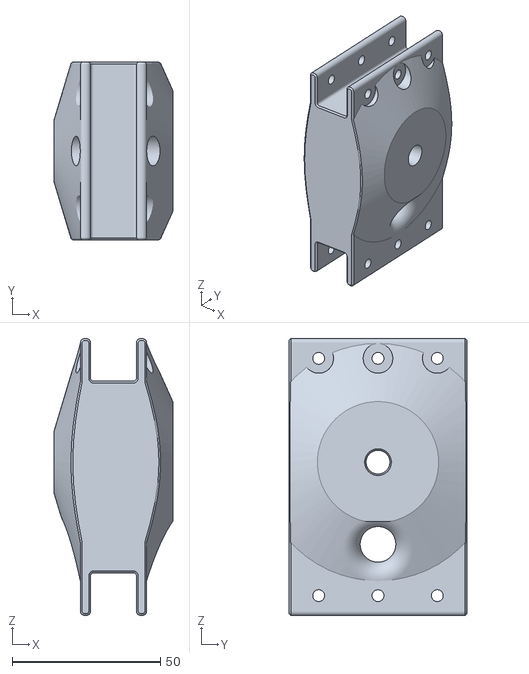
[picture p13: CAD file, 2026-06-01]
STL/Rocker Body Mount.stl
40.0 x 60.0 x 93.4

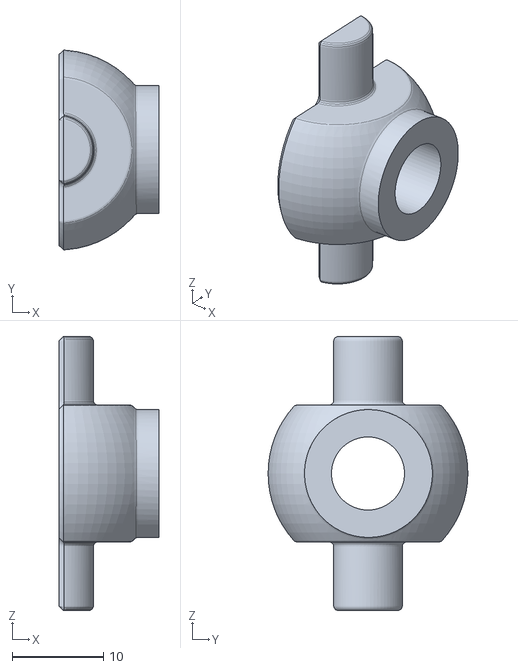
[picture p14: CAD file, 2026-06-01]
STL/Rod Support.stl
11.0 x 21.9 x 30.0

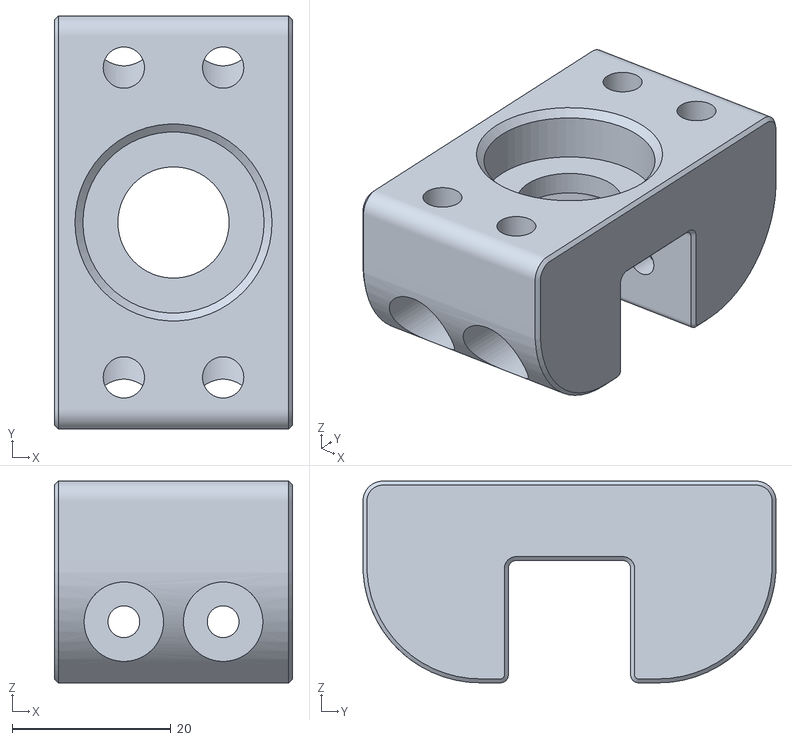
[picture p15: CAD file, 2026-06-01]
STL/DiffLower.stl
30.0 x 52.0 x 25.4

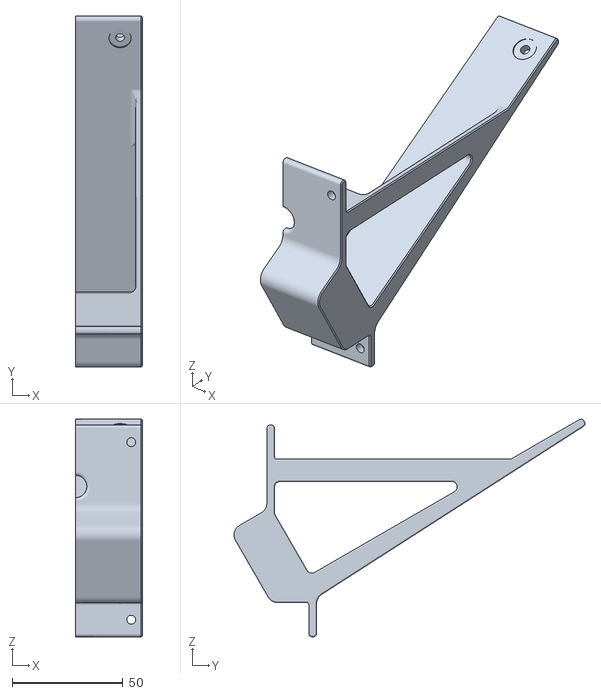
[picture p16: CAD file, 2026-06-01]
STL/Battery Tray.stl
30.0 x 158.1 x 98.0

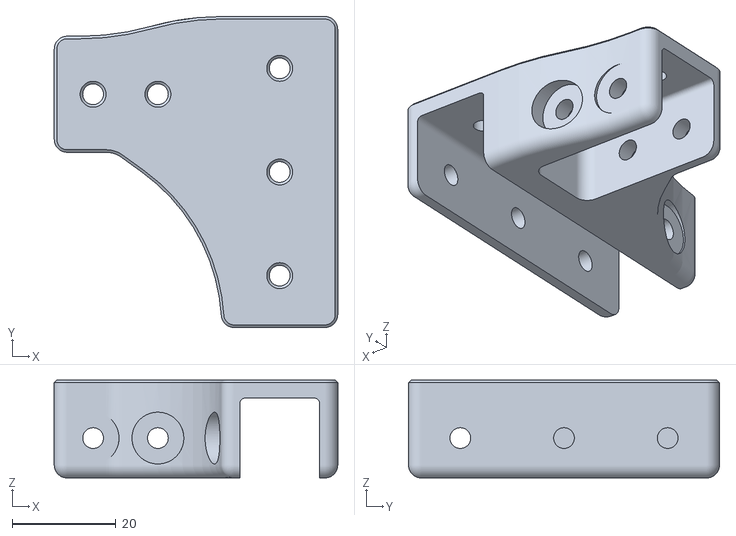
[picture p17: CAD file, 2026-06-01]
STL/DiffEnd.stl
54.7 x 60.0 x 18.9

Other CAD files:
PCB/Motor driver/3d flies/3D_Motor-Driver.step
Step-files/servo coupler.step
STL/Bogie-Body.stl
STL/Bogie-Wheels.stl
STL/Body Corner.stl
STL/Clip2n125.stl
STL/Clip3n20.stl
STL/DiffBrace.stl
STL/Fixed Knuckle.stl
STL/Front Corner.stl
STL/Rocker.stl
STL/Steering Knuckle.stl
STL/Wheel Hub.stl
STL/servo - Coupler.stl
STL/servo bracket.stl

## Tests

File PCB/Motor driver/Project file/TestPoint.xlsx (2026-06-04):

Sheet: Summary
Nets Total | 96
Has Testpoint Nets | 0
No Testpoint Nets | 96
Testpoint Coverage | 0%
Top Side Testpoints | 0
Bottom Side Testpoints | 0
Test Point Count | Testpoints Count
Net Count | Net Count

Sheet: Nets Count
Net Name | Quanatity
GND | 0
PWR | 0
PWR_AB | 0
PWR_CD | 0
$2N397 | 0
$2N415 | 0
$2N8816 | 0
$1N1664 | 0
12V | 0
$1N1857 | 0
$1N2033 | 0
$1N2177 | 0
$1N5497 | 0
$1N2316 | 0
$1N5477 | 0
$1N5435 | 0
$1N2538 | 0
$1N5444 | 0
$1N2583 | 0
3V3 | 0
PWR_CONN | 0
PICO_SCL0 | 0
PICO_SDA0 | 0
$1N1372 | 0
$1N1363 | 0
$1N1456 | 0
$1N2493 | 0
$1N3603 | 0
$2N571 | 0
$2N434 | 0
$2N2962 | 0
$2N2981 | 0
VREF | 0
FB | 0
$2N2016 | 0
$2N2012 | 0
$2N1539 | 0
$2N2107 | 0
$2N2141 | 0
$2N1741 | 0
$3N56672 | 0
$3N56615 | 0
5V | 0
$2N4199 | 0
$2N5028 | 0
$2N4095 | 0
$2N4706 | 0
$2N4701 | 0
$2N4806 | 0
$3N51883 | 0
$3N51879 | 0
$3N52120 | 0
I2C1_PULLUP_EN | 0
$3N52122 | 0
PICO_SCL1 | 0
$3N57148 | 0
$3N57149 | 0
$3N57150 | 0
$3N57175 | 0
$3N57159 | 0
$3N57160 | 0
DRIVER_OTW | 0
DRIVER_FAULT | 0
DRIVER_PWM_B | 0
DRIVER_RESET_AB | 0
DRIVER_PWM_A | 0
DRIVER_PWM_C | 0
DRIVER_RESET_CD | 0
DRIVER_PWM_D | 0
ACS722_OUT1 | 0
ACS722_OUT2 | 0
VIN_ADC | 0
SWDIO | 0
SWCLK | 0
I2C0_PULLUP_EN | 0
PICO_SDA1 | 0
PICO_SPI_CS | 0
PICO_SPI_MISO | 0
PICO_SPI_MOSI | 0
$3N57295 | 0
$3N57292 | 0
+5V | 0
$3N57297 | 0
$3N57317 | 0
$3N57299 | 0
$3N57274 | 0
$3N57273 | 0
$3N57281 | 0
CAN_CS | 0
PICO_SPI_SCK | 0
CAN_INT | 0
$3N57284 | 0
$3N57283 | 0
$3N57286 | 0
$3N57285 | 0
$3N57321 | 0

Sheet: Testpoints Count
Number | Net | Center X | Center Y | Layer | Hole Size

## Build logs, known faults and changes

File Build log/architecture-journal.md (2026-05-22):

# Architecture Journal  Bumblebee Rover

> This document records every major hardware decision made during the Bumblebee build  why we chose what we chose, why we rejected the alternatives, and what to do if you can't find the exact part. Written for builders in Bangladesh and similar hardware-constrained environments.

---

## 1. Drive Motor  JGB37-520 12V 100RPM DC Gear Motor

### Why this
The JGB37-520 is a metal-gearbox DC gear motor with a D-shaft output, widely available in Bangladesh from local electronics markets and online sellers. At 12V 100RPM it delivers enough torque to move a ~5kg rover chassis over uneven ground without stalling. The D-shaft is straightforward to couple to printed hubs. It is robust, repairable, and cheap enough to replace if one fails during testing.

### Why not the original (LX-16A Smart Servo)
The LX-16A is a serial bus smart servo that handles both drive and steering in the original Sawppy. It requires a proprietary TTL serial protocol, a specific controller board, and is expensive and difficult to source in Bangladesh. A single LX-16A costs more than the entire JGB37-520 drivetrain for this build. It also means 10 identical units for a 6-wheel drive + 4-steering configuration  the import cost alone makes it impractical.

### Why not other available options
- **Standard DC hobby motors (no gearbox)**  not enough torque at rover wheel speeds without external gearing. Would require additional mechanical complexity.
- **Stepper motors**  too heavy, inefficient for continuous rotation, overkill for this application, hard to source in the right form factor locally.
- **Worm gear motors**  self-locking behavior makes them unsuitable for a suspension system that needs to absorb terrain impacts through the drivetrain.
- **High-RPM DC motors with encoder**  RPM too high, torque too low without significant reduction gearing.

### If you can't find the JGB37-520
You need a **DC gear motor** with the following minimum specifications:

| Specification | Minimum | Recommended |
|---|---|---|
| Voltage | 6V | 12V |
| No-load speed | 50 RPM | 80–120 RPM |
| Stall torque | 5 kg·cm | 8–15 kg·cm |
| Shaft type | D-shaft or round with flat | D-shaft preferred |
| Shaft diameter | 6mm | 6mm |
| Body diameter | 37mm class | 37mm (fits existing mounts) |
| Gearbox | Metal | Metal (plastic will strip under load) |

Search for: **N20, N30, JGA25, GA25, JGB37 series** gear motors at your local electronics market. If the body diameter differs from 37mm you will need to reprint the motor brackets  the STEP files are parametric enough to adapt. Avoid motors with plastic gearboxes; they will strip under stall load.

---

## 2. Steering  Hiwonder LDX-277 PWM Servo

### Why this
Standard 25T spline PWM servo with enough torque to hold steering position under load. Compatible with every standard servo controller and the ESP32-C3 PWM output directly. The 25T spline is an industry standard  servo horns, couplers, and brackets are interchangeable with dozens of other brands. LDX-277 is sourceable in Bangladesh and the torque-to-cost ratio is good for this application.

### Why not the original (LX-16A Smart Servo)
Same reasons as drive  serial bus protocol, expensive, import-only, proprietary ecosystem.

### Why not other available options
- **MG996R / MG995**  very common and cheap, but torque rating is often inflated by manufacturers. Plastic gears in some variants. Acceptable as a fallback but not first choice.
- **Digital servos (high-end)**  unnecessary precision and cost for a steering application that only needs four positions (left, center-left, center-right, right range).
- **Linear actuators**  too slow for real-time steering response and mechanically complex to integrate into the existing knuckle geometry.

### If you can't find the LDX-277
You need a **standard PWM servo** with the following minimum specifications:

| Specification | Minimum | Recommended |
|---|---|---|
| Torque | 10 kg·cm | 15–20 kg·cm |
| Spline | 25T standard | 25T standard |
| Voltage | 5V | 6–7.4V |
| Protocol | PWM (50Hz) | PWM (50Hz) |
| Gear material | Metal | Metal |
| Body width | ~40mm | Standard servo form factor |

Search for: **MG996R, DS3218, LX-225, Hitec HS-485HB** or any servo labeled "25T metal gear standard size." If torque is below 10 kg·cm the servo will skip under cornering load. The 25T spline is critical  if you use a servo with a different spline count (for example 24T or 23T) the printed couplers will not fit and you will need to reprint them.

---

## 3. Motor Driver  BTS7960 43A H-Bridge Module

### Why this
The BTS7960 is a high-current half-bridge driver chip. On a module it forms a full H-bridge capable of 43A peak, 14A continuous per channel. The JGB37-520 can draw 5–10A at stall  the BTS7960 handles this without browning out or burning. Standard PWM input, 12V compatible, available in Bangladesh, and cheap. Three modules handle all six drive motors in pairs (front pair, middle pair, rear pair).

### Why not DRV8833
The DRV8833 is a dual H-bridge rated at 1.5A continuous, 2A peak per channel. The JGB37-520 stall current exceeds this by a factor of 3–5×. Under real terrain load the DRV8833 would trigger thermal shutdown or burn out. It is the right choice for small hobby motors but wrong for this drivetrain.

### Why not other available options
- **L298N**  old design, very inefficient (up to 3V drop across the driver), runs extremely hot, wastes battery. Functional but wasteful.
- **L293D**  600mA per channel, completely insufficient for this application.
- **IBT-2 module**  essentially the same as BTS7960 (same chip), just a different PCB layout. Fully compatible substitute.
- **Sabertooth / Kangaroo**  capable but expensive, overkill, and harder to source locally.

### If you can't find the BTS7960
You need a **motor driver module** with the following minimum specifications:

| Specification | Minimum | Recommended |
|---|---|---|
| Continuous current per channel | 10A | 15A+ |
| Peak current per channel | 20A | 43A |
| Operating voltage | 12V | 6–27V range |
| Input signal | PWM | PWM (3.3V logic compatible) |
| Heat dissipation | Heatsink required | Heatsink + airflow |

Direct substitute: **IBT-2 module** (identical chip, different board layout  fully pin-compatible).
Acceptable fallback: **L298N** (inefficient but functional  expect heat and reduced battery life).
Search for: BTS7960, IBT-2, "43A motor driver module" on local markets or AliExpress.

Wiring note: 3 drivers for 6 motors. Each driver uses 4 GPIO pins (RPWM, LPWM, R_EN, L_EN). Total GPIO used for drive: **12 pins** from the ESP32-C3.

---

## 4. Low-Level MCU  XIAO ESP32-C3 (or Arduino fallback)

### Why this
The XIAO ESP32-C3 is a compact, low-cost microcontroller with enough GPIO for PWM servo control, motor driver signals, and IMU communication over I2C. It handles the real-time control loop: reading the MPU-6050, outputting PWM to servos, sending PWM + enable signals to the BTS7960 drivers, and communicating with the Raspberry Pi over UART or USB serial. Small footprint, 3.3V logic (compatible with BTS7960 input), Wi-Fi capable for debugging.

### Why not Arduino Uno / Nano
Arduino is a completely valid fallback and simpler to program for beginners. The Uno/Nano runs at 5V logic which requires level shifting to interface with 3.3V peripherals. It has fewer GPIO pins and no Wi-Fi. For the basic control loop it works fine  it just needs a logic level converter between the Arduino and the BTS7960 if using a 5V board.

**Arduino is the recommended fallback** if you cannot source the XIAO ESP32-C3 or are not comfortable with ESP-IDF / Arduino-ESP32 framework.

### Why not other available options
- **STM32 Bluepill**  capable but complex toolchain setup, harder to find working USB bootloaders locally, steeper learning curve.
- **Teensy**  excellent but expensive and import-only in Bangladesh.
- **Raspberry Pi Pico**  good alternative, 3.3V logic, dual-core, MicroPython or C SDK. Viable substitute if ESP32-C3 is unavailable.
- **NodeMCU ESP8266**  lacks enough GPIO for this application (6 motor driver signals + 4 servo signals + I2C = tight), and no hardware PWM on enough pins.

### If you can't find the XIAO ESP32-C3
You need a **microcontroller** with the following minimum specifications:

| Specification | Minimum | Recommended |
|---|---|---|
| PWM-capable GPIO pins | 16 | 20+ |
| I2C | 1 bus | 1 bus |
| UART | 1 port | 1 port (for Pi communication) |
| Logic voltage | 3.3V or 5V | 3.3V (check BTS7960 input spec) |
| Clock speed | 16 MHz | 80–240 MHz |

Acceptable substitutes in order of preference:
1. **Arduino Mega 2560**  most GPIO, easy to source, 5V (use level shifter for BTS7960)
2. **Raspberry Pi Pico**  3.3V, dual-core, MicroPython friendly
3. **Arduino Uno/Nano**  limited pins but works for basic control loop
4. **ESP32 DevKit (30-pin)**  direct ESP32 family substitute, more GPIO than XIAO

---

## 5. Single Board Computer  Raspberry Pi (any model 3B+, 4, or Zero 2W)

### Why this
The Raspberry Pi runs the high-level autonomy stack: ROS 2, GPS navigation, SLAM, camera processing, and mission planning. It communicates with the ESP32-C3 (low-level MCU) over UART or USB serial  the Pi sends movement commands, the ESP32 executes them in real time. This separation keeps the real-time control loop on dedicated hardware and the compute-heavy autonomy stack on Linux.

### Why not run everything on the Pi
The Raspberry Pi Linux OS is not a real-time operating system. PWM timing, motor control loops, and servo signals require microsecond-level precision that Linux cannot guarantee. Running motor drivers directly from Pi GPIO is unreliable under CPU load. The ESP32-C3 handles everything time-critical; the Pi handles everything compute-heavy.

### Why not other available options
- **Jetson Nano**  more powerful for computer vision and ML inference, but expensive, harder to source in Bangladesh, and overkill for initial navigation stack.
- **Orange Pi / Banana Pi**  viable substitutes if Raspberry Pi is unavailable. ROS 2 support is less mature but workable on Ubuntu ARM builds.
- **Beaglebone Black**  real-time PRU cores are interesting but ROS 2 ecosystem support is weaker.
- **Old laptop/PC**  too heavy, too power-hungry for a rover platform.

### If you can't find a Raspberry Pi
You need a **single board computer** with the following minimum specifications:

| Specification | Minimum | Recommended |
|---|---|---|
| CPU | Quad-core ARM Cortex-A | Cortex-A53 or better |
| RAM | 1 GB | 2–4 GB |
| OS | Linux (Ubuntu/Debian ARM) | Ubuntu 22.04 ARM |
| USB | 1× USB 2.0 | 2× USB |
| UART / GPIO | Available | For ESP32 communication |
| Power consumption | <10W | <8W |

Acceptable substitutes:
1. **Orange Pi 3 LTS / Orange Pi 5**  good ROS 2 support, available in Bangladesh
2. **Radxa Rock 3**  Ubuntu support, similar form factor
3. **Raspberry Pi Zero 2W**  lower power, less RAM, still runs ROS 2 lite
4. Any SBC running **Ubuntu 22.04 ARM** with ROS 2 Humble packages available

---

## 6. IMU  MPU-6050

### Why this
6-axis IMU (3-axis accelerometer + 3-axis gyroscope) over I2C. Cheap, universally available everywhere in Bangladesh, well-supported in every Arduino and ESP32 library ecosystem. Sufficient for basic orientation estimation and tilt detection on the rover.

### Why not other available options
- **MPU-9250**  adds magnetometer, better for absolute heading but harder to source and more expensive. Upgrade path, not necessary for initial build.
- **BNO055**  has onboard sensor fusion which simplifies firmware but costs significantly more.
- **ADXL345 (accelerometer only)**  no gyro, insufficient for dynamic orientation estimation.

### If you can't find the MPU-6050
Any **I2C IMU module** with the following:

| Specification | Minimum |
|---|---|
| Axes | 6DOF (accel + gyro) |
| Interface | I2C |
| Voltage | 3.3V or 5V with onboard regulator |
| Library support | Arduino / ESP32 compatible |

Substitutes: **MPU-9250, GY-521 (same chip as MPU-6050), ICM-20600, LSM6DS3**. The GY-521 module IS the MPU-6050 on a breakout board  they are the same thing with different labels.

---

## Decision Summary

| Component | Chosen | Rejected | Key reason |
|---|---|---|---|
| Drive motor | JGB37-520 | LX-16A smart servo | Cost, local availability, D-shaft simplicity |
| Steering | LDX-277 PWM servo | LX-16A smart servo | Standard 25T spline, PWM compatible |
| Motor driver | BTS7960 | DRV8833, L298N | Stall current handling (43A peak) |
| Low-level MCU | XIAO ESP32-C3 | Arduino Uno, STM32 | GPIO count, 3.3V logic, compact size |
| MCU fallback | Arduino Mega |  | Easy to source, simple toolchain |
| SBC | Raspberry Pi | Jetson Nano, Orange Pi | ROS 2 ecosystem, local availability |
| IMU | MPU-6050 | BNO055, MPU-9250 | Universal availability, I2C, cheap |

---

*Last updated: May 2026*
*Bumblebee is fiscally sponsored by [Hack Club HCB](https://hcb.hackclub.com/donations/start/bumblebee) · 501(c)(3) · EIN 81-2908499*

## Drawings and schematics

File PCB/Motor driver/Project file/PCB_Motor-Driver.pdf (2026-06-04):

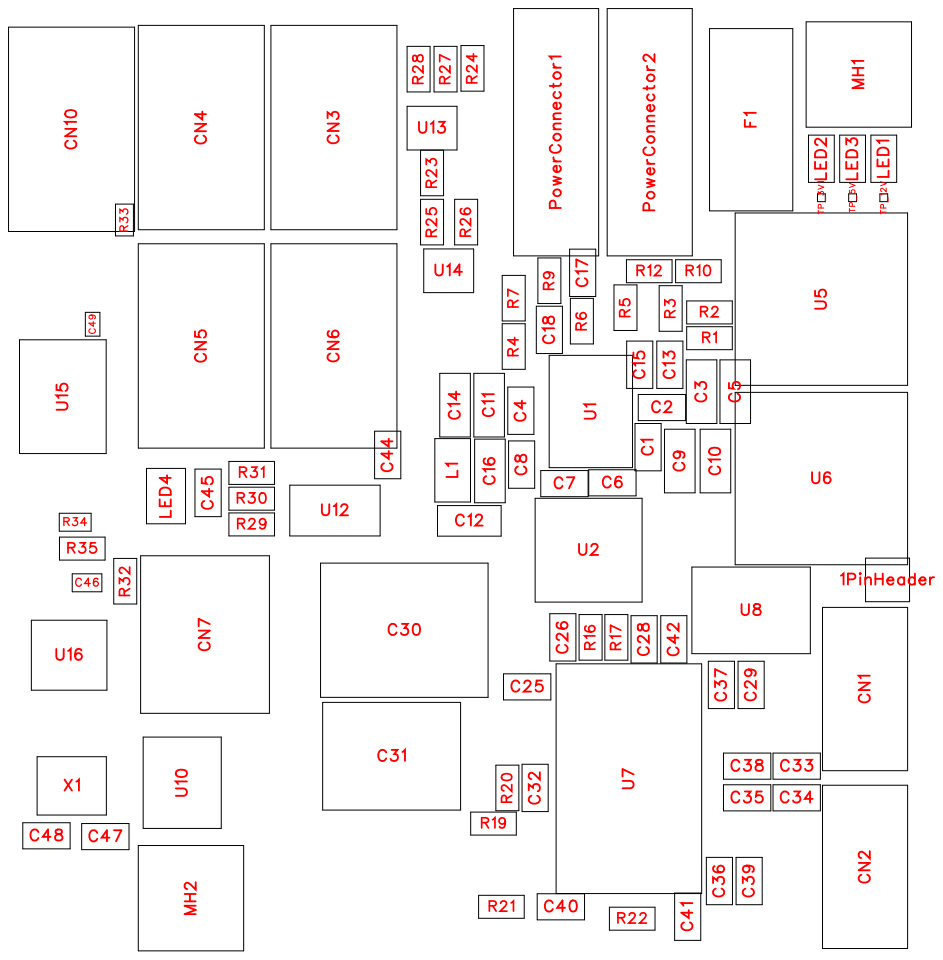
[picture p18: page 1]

C33
C35 | C34

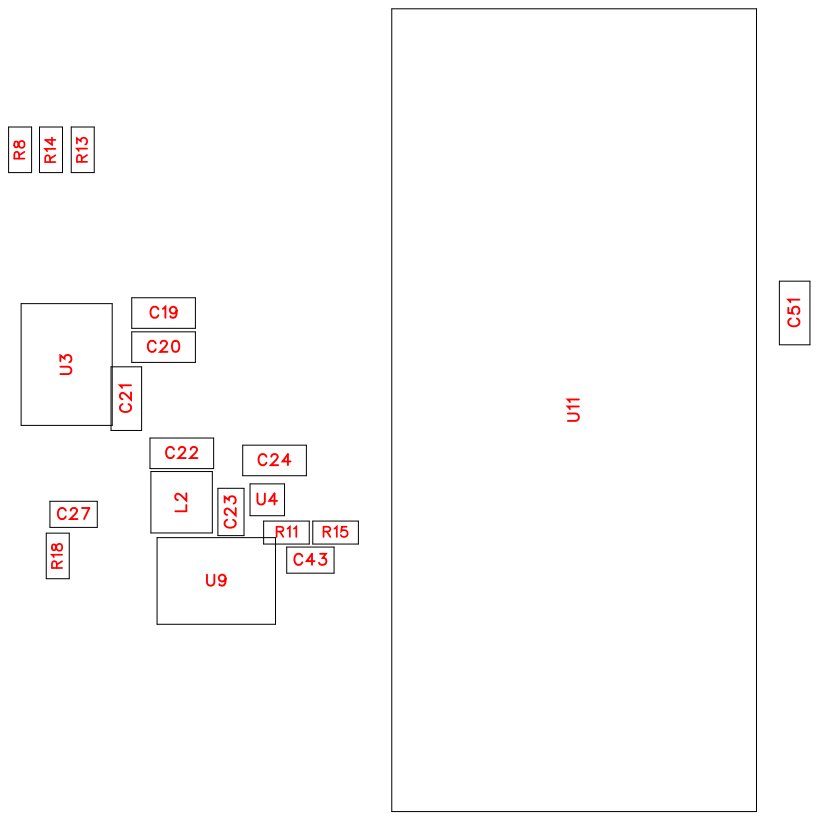
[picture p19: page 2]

No. | Quantity | Comment | Designator | Footprint | Value | Manufacturer Part | Manufacturer | Supplier Part | Supplier
1 | 1 | 1PinHeader | 1PinHeader | 1PinHeader
2 | 15 | 100nF | C1,C2,C4,C6,C7,C8,C18,C 23,C32,C35,C36,C37,C38, C42,C43 | C0603 | 100nF | CL10B104KB 8NNNC | SAMSUNG( 三星) | C1591 | LCSC
3 | 4 | 10uF | C3,C5,C9,C10 | C0805 | 10uF
4 | 9 | 22uF | C11,C12,C14,C16,C19,C20 ,C21,C22,C24 | C0805 | 22uF | CL21A226M AYNNNE | SAMSUNG( 三星) | C602037 | LCSC
5 | 1 | 4.7uF | C13 | C0603 | 4.7uF
6 | 1 | 470nF | C15 | C0603 | 470nF
7 | 1 | 22nF | C17 | C0603 | 22nF
8 | 9 | 1uF | C25,C26,C28,C29,C33,C34 ,C39,C40,C41 | C0603 | 1uF | CL10A105KA 8NNNC | SAMSUNG( 三星) | C5673 | LCSC
9 | 1 | 10nF | C27 | C0603 | 10nF
10 | 1 | 330uF | C30 | CAP-SMD_B D8.0-L8.3-W 8.3-FD | 330uF | EMK1EM331 FB0D00R | AISHI(艾华集 团) | C5289732 | LCSC
11 | 1 | 47uF | C31 | CAP-SMD_B D6.3-L6.6-W 6.6-LS7.8-FD | 47uF | EEV476M03 5S9GAA | KEMET(基美 ) | C3829743 | LCSC
12 | 2 | 100nF | C44,C45 | C0603 | | 0603F104Z5 00CT | Walsin(华新 科) | C83060 | LCSC
13 | 1 | 100nF | C46 | C0402 | 100nF | FN15B104K2 50PNG | PSA(信昌电 陶) | C394158 | LCSC
14 | 2 | 22pF | C47,C48 | C0603 | 22pF | 0603N220G5 00CT | Walsin(华新 科) | C388039 | LCSC
15 | 1 | 100nF | C49 | C0201 | 100nF | FN03B104K1 60PLG | PSA(信昌电 陶) | C525189 | LCSC
16 | 1 | 100nF | C51 | C0805 | 100nF | CC0805KRX 7R9BB104 | YAGEO(国巨 ) | C49678 | LCSC
17 | 2 | XT30U-M | CN1,CN2 | CONN-TH_X T30U-M | | XT30U-M | AMASS(艾迈 斯) | C99101 | LCSC
18 | 5 | WAFER-PH2 .0-4PLB | CN3,CN4,CN5,CN6,CN10 | CONN-SMD_ 4P-P2.00_W AFER-200L-4A | | WAFER-PH2 .0-4PLB | XUNPU(讯普 ) | C3029433 | LCSC
19 | 1 | 98424-G52-0 6ALF | CN7 | CONN-SMD_ 98424-G52-0 6ALF | | 98424-G52-0 6ALF | Amphenol | C180222 | LCSC
20 | 1 | 0154001.DR | F1 | FUSE-SMD_ L9.8-W5.1 | | 0154001.DR | Littelfuse(美 国力特) | C206908 | LCSC
21 | 1 | MPZ2012S2 21ATD25 | L1 | L0805 | | MPZ2012S2 21ATD25 | TDK | C307778 | LCSC
22 | 1 | ME3220-472 MLC | L2 | IND-SMD_L3 .2-W2.8 | | ME3220-472 MLC | Coilcraft(线艺 ) | C19276064 | LCSC
23 | 3 | LED_0603-R | LED1,LED2,LED3 | LED0603-R-RD

24 | 1 | 150066M153 000 | LED4 | 150066M153 000
25 | 2 | M3 Screw | MH1,MH2 | MOUNTING HOLE-M3 | | M3 Screw
26 | 2 | XT30(2+2)P B-M.G.B | PowerConnector1,PowerCo nnector2 | CONN-TH_X T30PB-M | | XT30(2+2)P B-M.G.B | AMASS(艾迈 斯) | C19268029 | LCSC
27 | 1 | 120k | R1 | R0603 | 120k
28 | 4 | 100k | R2,R3,R5,R10 | R0603 | 100k
29 | 1 | 110k | R4 | R0603 | 110k
30 | 1 | 5.1k | R6 | R0603 | 5.1k
31 | 3 | 10K | R7,R12,R15 | R0603 | 10K
32 | 1 | 4.7k | R8 | R0603 | 4.7k
33 | 1 | 143k | R9 | R0603 | 143k
34 | 1 | 53k | R11 | R0603 | 53k
35 | 1 | 1k | R13 | R0603 | 1k
36 | 1 | 2k | R14 | R0603 | 2k
37 | 4 | 5R | R16,R17,R21,R22 | R0603 | 5R
38 | 1 | 3R3 | R18 | R0603 | 3R3
39 | 1 | 24K | R19 | R0603 | 24K
40 | 1 | 1R | R20 | R0603 | 1R
41 | 4 | 4k7 | R23,R24,R25,R26 | R0603 | 4k7
42 | 2 | 0R | R27,R28 | R0603 | 0R
43 | 3 | 1k | R29,R30,R31 | R0603 | 1k | RT0603BRD 071KL | YAGEO(国巨 ) | C110776 | LCSC
44 | 1 | 10k | R32 | R0603 | 10k | 0603WAF10 02T5E | UNI-ROYAL( 厚声) | C25804 | LCSC
45 | 1 | 120 | R33 | R0402 | 120 | 0402WGF12 00TCE | UNI-ROYAL( 厚声) | C25079 | LCSC
46 | 1 | 2.2k | R34 | R0402 | 2.2k | RMC04022.2 K1%N | Tyohm(幸亚 电阻) | C325418 | LCSC
47 | 1 | 3.3k | R35 | R0603 | 3.3k | RMC06033.3 K1%N | Tyohm(幸亚 电阻) | C269710 | LCSC
48 | 3 | Test-Point | TP_3V1,TP_5V,TP_12V | Test-Point-0. 5mm
49 | 1 | LT8350RV#P BF | U1 | LQFN-32_L6. 0-W4.0-P0.5 0-BL-EP_LT8 350RV | | LT8350RV#P BF | ADI(亚德诺) | C5367366 | LCSC
50 | 1 | 6.8uH | U2 | IND-SMD_L6 .6-W6.4 | 6.8uH | XAL6060-68 2MEC | Coilcraft(线艺 ) | C5355913 | LCSC
51 | 1 | BD33HC0VE FJ-ME2 | U3 | HTSOP-J8_L 4.9-W3.9-P1. 27-LS6.0-BL-EP | | BD33HC0VE FJ-ME2 | ROHM(罗姆) | C22202420 | LCSC
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

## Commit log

2026-05-11 Upload Wheel.step
2026-05-11 Upload all Rover STEP files to repository root
    [Bogie-Body.step, Bogie-Wheels.step, Clip2n125.step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]
2026-05-11 Upload Step Files folder with all CAD models
2026-05-11 Rename Body Corner.step to Step-files/Body Corner.step
    [Body Corner.step]
2026-05-11 Rename Fixed Knuckle.step to Step-files/Fixed Knuckle.step
    [Fixed Knuckle.step]
2026-05-11 Rename Front Corner.step to Step-files/Front Corner.step
    [Front Corner.step]
2026-05-11 Rename Power Panel.step to Step-files/Power Panel.step
    [Power Panel.step]
2026-05-11 Rename Rear Corner.step to Step-files/Rear Corner.step
    [Rear Corner.step]
2026-05-11 Rename Rocker Body Mount.step to Step-files/Rocker Body Mount.step
    [Rocker Body Mount.step]
2026-05-11 Rename Rod Support.step to Step-files/Rod Support.step
    [Rod Support.step]
2026-05-11 Rename Steering Knuckle.step to Step-files/Steering Knuckle.step
    [Steering Knuckle.step]
2026-05-11 Rename Wheel Hub.step to Step-files/Wheel Hub.step
    [Wheel Hub.step]
2026-05-11 Rename servo bracket.step to Step-files/servo bracket.step
    [servo bracket.step]
2026-05-11 Rename servo coupler.step to Step-files/servo coupler.step
    [servo coupler.step]
2026-05-22 Create Bill of Materials for Bumblebee Rover
    Added a comprehensive Bill of Materials for the Bumblebee Rover, detailing printed parts, shafts, hardware, electronics, and aluminum extrusion requirements.
2026-06-01 Add README with Bill of Materials for Bumblebee Rover
    Added a Bill of Materials for the Bumblebee Rover, detailing printed parts and quantities required for assembly.
2026-06-04 Add motor driver STEP file
    [3D_Motor-Driver.step]
